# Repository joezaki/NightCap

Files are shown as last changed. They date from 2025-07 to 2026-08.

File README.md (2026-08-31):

# NightCap

> ### NightCap is a tool for constructing custom electrophysiology implants for performing multi-site electrophysiology. Given a set of stereotaxic coordinates for up to 16 brain regions, this pipeline will produce a 3D-printable implant along with a custom electrode interface board (EIB) where holes in both are stereotaxically defined.

#### *Note: NightCap was made initially for performing long-term electrophysiology for sleep studies; however, this tool can be applied as readily to any chronic electrophysiology setup.*
***

## *Procedure*
### *General Overview*

> 1.  First, create a CSV file of stereotaxic locations with the following columns: `['Region', 'AP', 'ML', 'DV', 'Type']`.
> 1. Type should be one of `['LFP', 'GND', 'REF', 'EEG', 'EMG']`.
> 1. Save this file to the `StereotaxCoords` folder.
> 1. Proceed to `Implant` instructions below to construct the 3D-printable implant.
> 1. Proceed to `PCB`, `Bottom PCB`, and `Top PCB` instructions to construct the bottom and top PCBs.
> 1. Proceed to `Assembly` to put everything together.<br>
> *Note: Images below are examples from running the pipeline on the CSV provided in the repo: `./StereotaxCoords/CTX_TH_HPC_Bilateral_16Ch.csv`*

***

### *Implant*
> 1. We will be using OpenSCAD to construct the 3d-printable STL files. [Install OpenSCAD here.](https://openscad.org) *Note that you may first have to allow your computer to trust the program before you can open it.*
> 1. In the `Implant` sub-folder, open the `generate_implant.py` file in a text editor. In the `Specify parameters` section, update `brain_regions_csv` with the filename of your stereotaxic coordinates file. Modify any other parameters of interest here.
> 1. Open a terminal window, navigate to where you cloned the `NightCap` folder: `cd ~/path/to/NightCap`
> 1. Create the conda environment: `conda env create -f environment.yml`<br>*Note: If you do not have conda installed on your computer, [install Anaconda here](https://anaconda.org) first.*
> 1. Activate environment: `source activate nightcap`
> 1. Execute script: `python generate_implant.py`. It may take a few minutes to run. The terminal window will print statements as the pipeline progresses.
> 1. A folder called `./GeneratedFiles/Implant` should have been created. Check inside this folder for a folder with the current time. Inside this folder should be:

| File/Folder | Description |
| --- | --- |
| `implant.stl` & `depth_guide.stl` | 3D-printable STL files |
| `implant.scad` & `depth_guide.scad` | SCAD files for constructing STL files |
| `regions.csv` | original stereotaxic coordinates CSV |
| `implant_depth_guide.html`  | interactive visualization of the stl files for the implant and depth guide |
| `2d_implant.html` & `3d_implant.html`  | interactive visualizations of the implant mapping |
| `3d_implant_animation.gif` | GIF of the 3D rotating implant for presentations (optional) |

<div align="center">
    implant_depth_guide<br>
    2d_implant<br>
    3d_implant<br>
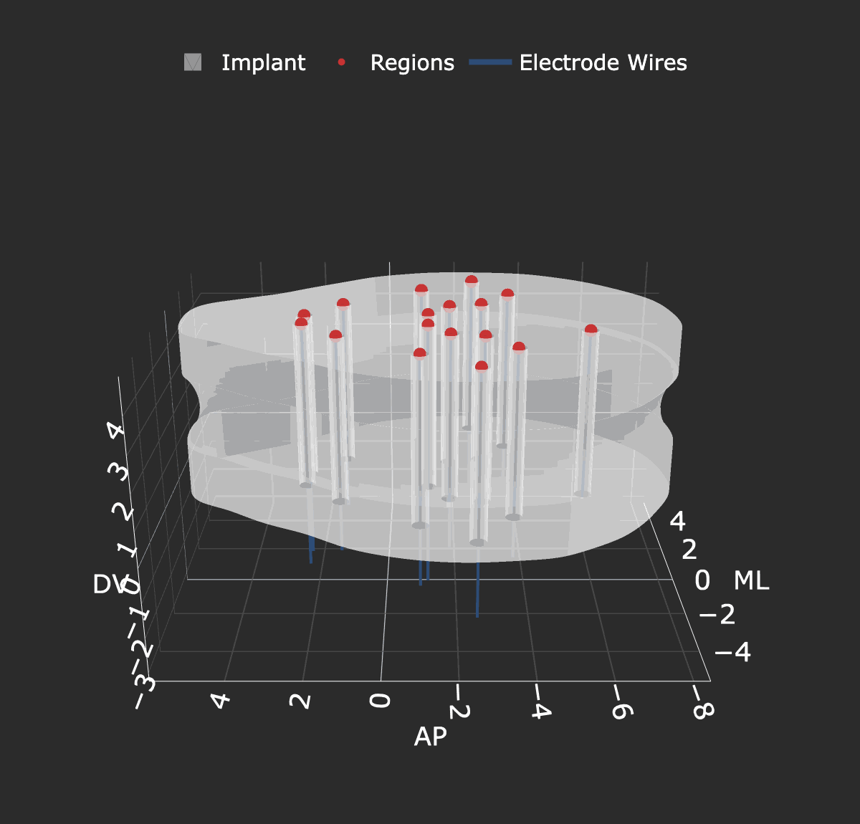
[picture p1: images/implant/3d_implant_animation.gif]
3d_implant_animation
    
</div>

***

### *PCB*
> 0. Only perform the following two steps prior to first use of this pipeline:
> 1. For PCB construction, we will use the KiCad software. [Install KiCad here.](https://kicad.org)
> 1. After installing KiCad, install the Freerouting plugin:
> > - Open KiCad
> > - `Tools -> Plugin and Content Manager`
> > - Find "Freerouting" and install.
> > - Click "Apply Pending Changes"
> > - [Install Java here.](https://adoptium.net/temurin/releases)
> > - After installation, restart KiCad.

***

### *Bottom PCB*
> 1. In the `BottomPCB` subfolder, open `generate_bottom_pcb.py` file in a text editor. In the `Specify parameters` section, update `brain_regions_csv` with the filename of your stereotaxic coordinates file. Modify any other parameters of interest here.
> 1. In KiCad, open project by clicking on `.../NightCap/PCB/BottomPCB/BottomPCB.kicad_pro`
> 1. Click on PCB Editor. A blank window should pop up.
> 1. `Tools -> Scripting Console`
> 1. Execute script: `exec(open('./generate_bottom_pcb.py').read())`
> 1. A folder should have been created in `./GeneratedFiles/BottomPCB/` with the current time. Inside this folder should be:

| File/Folder | Description |
| --- | --- |
| `NightCap_BottomPCB_JLCPCB_Production.zip` | main file to upload to JLCPCB for PCB construction |
| `NightCap_BottomPCB_Gerbers/` | folder with gerber files for PCB construction |
| `channel_map.csv` | mapping between each brain region and the EIB channel |
| `autoroute.ses` | file with autorouting track data |
| `figures/` | folder with visualizations of PCB |

<div align="center">
    bottom_pcb_top_view
    bottom_pcb_bottom_view
</div>

***

### *Top PCB*
> 1. In the `TopPCB` subfolder, open `generate_top_pcb.py` file in a text editor. In the `Specify parameters` section, update `which_connector` to be one of `['molex', 'omnetics']`. Modify any other parameters of interest here.
> 1. In KiCad, open project by clicking on `.../NightCap/PCB/TopPCB/TopPCB.kicad_pro`
> 1. Click on PCB Editor. A blank window should pop up.
> 1. `Tools -> Scripting Console`
> 1. Execute script: `exec(open('./generate_top_pcb.py').read())`
> 1. A folder should have been created in `./GeneratedFiles/TopPCB/` with the current time. Inside this folder should be:

| File/Folder | Description |
| --- | --- |
| `NightCap_TopPCB_JLCPCB_Production.zip` | main file to upload to JLCPCB for PCB construction |
| `NightCap_TopPCB_Gerbers/` | folder with gerber files for PCB construction |
| `NightCap_TopPCB_BOM.csv` | file for bill of materials for connector (molex or omnetics) |
| `NightCap_TopPCB_positions.csv` | file placement position for connector onto PCB |
| `autoroute.ses` | file with autorouting track data |
| `figures/` | folder with visualizations of PCB |

<div align="center">
    top_pcb_top_view
    top_pcb_bottom_view
</div>

***

### *Assembly*
> 0. After following the steps above, the implant and depth guide need to be 3D-printed (we use the FormLabs Form4), and the Top and Bottom PCBs need to be constructed (we use [JLCPCB](https://jlcpcb.com)).
> 1. Once implant, depth guide, top PCB, and bottom PCB have been created, the whole implant needs to be assembled.
> 1. First, take wire of your choosing (we have been using [Stablohm 650 wire](https://calfinewire.com/item/alloys/all-alloys/100187-stablohm-650-wire) for LFP wires and [PFA-Coated Silver Wire 786000](https://www.a-msystems.com/p-796-pfa-coated-silver-wire.aspx) for EEG and EMG wires).
> 1. Cut each wire to ~20mm long using sharp scissors, and strip 1mm of insulation off one end of each wire. This side will connect to the bottom PCB.
> 1. Feed header pins into each outer via on the bottom PCB and solder into place.
> 1. Attach implant onto bottom PCB.
> 1. Secure depth guide onto the implant. Look top down through the bottom PCB to make sure that all the holes align.
> 1. Feed each wire through the holes in the bottom PCB. They should feed cleanly through the bottom PCB, implant, and depth guide. Solder them in place.
> 1. Line up the top PCB over the bottom PCB using the header pins. Solder the pins in place.
> 1. At this point, the impedance of each electrode is tested by submerging the signal and ground wires into saline and running a program to test impedances.
> 1. Snip the wires to length at the point at which they exit the depth guide, using sharp scissors.
> 1. Remove the depth guide.
> 1. The implant is now ready for implantation. Finally, the implant is surgically implanted into the subject for recording.

### Happy recording! :sparkles:

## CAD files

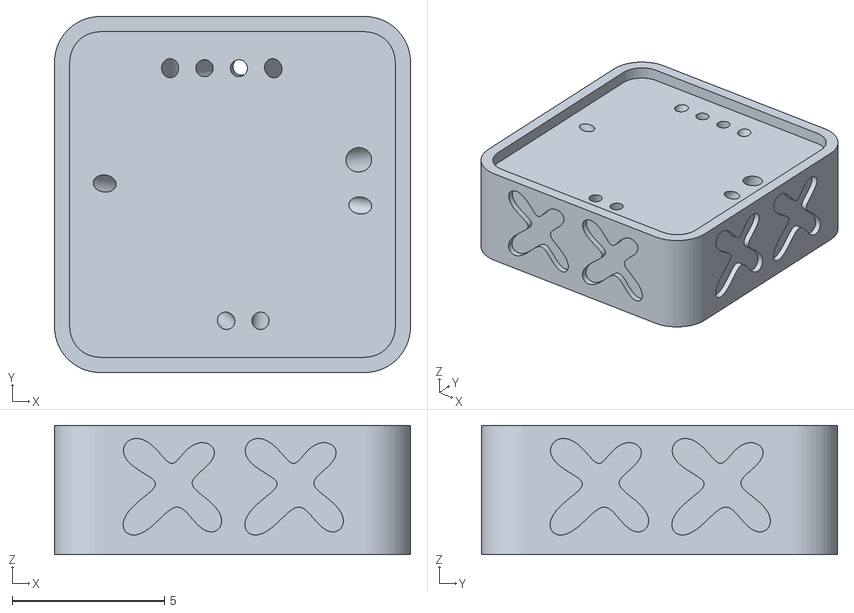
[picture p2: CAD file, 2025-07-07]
EIB16MouseImplantCompleted.stl
11.7 x 11.7 x 4.25

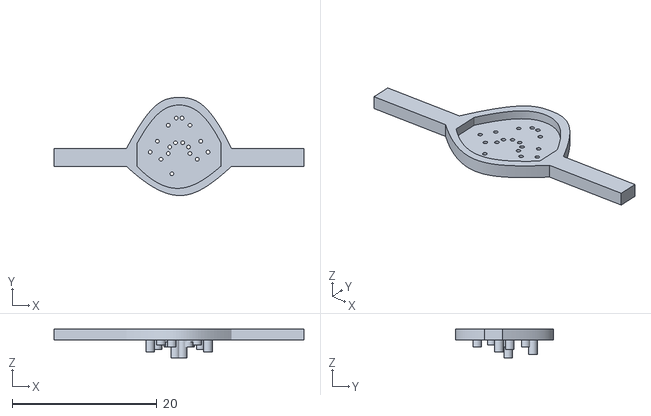
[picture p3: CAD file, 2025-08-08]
DepthTestCortex2_8825.stl
34.6 x 13.6 x 4.00

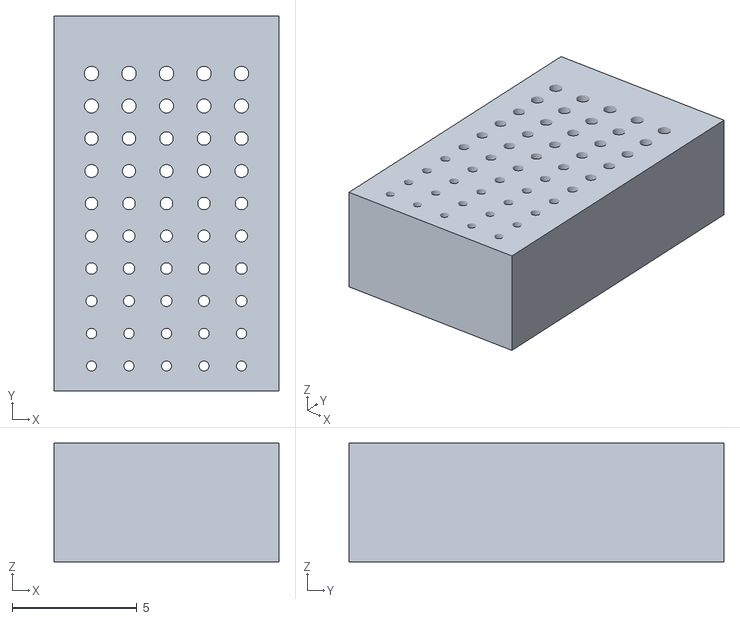
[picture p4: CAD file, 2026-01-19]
Implant/3D_PrinterTests/NightCap_HoleSizeTest_0.20_0.29_range.stl
9.00 x 15.0 x 4.75

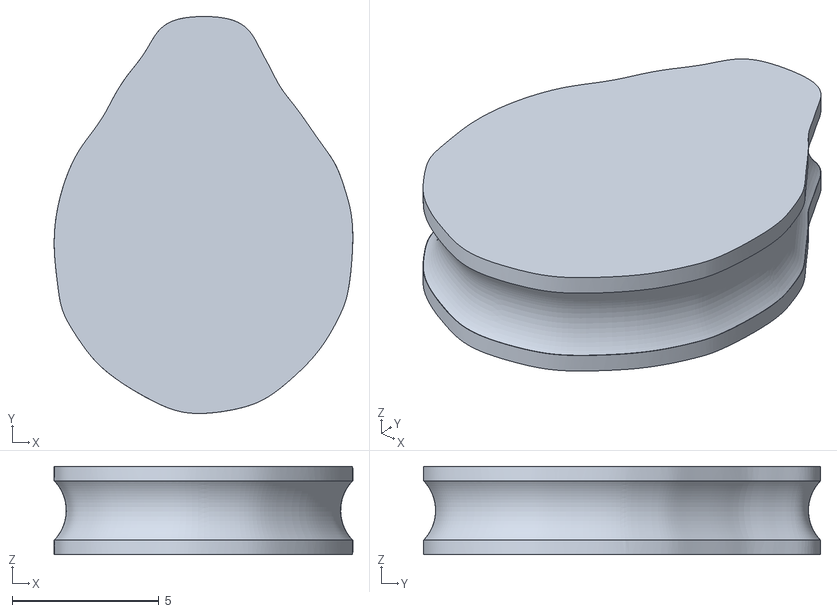
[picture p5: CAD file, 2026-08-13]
Implant/SCAD_Files/ImplantBlank_H3mm.stl
10.2 x 13.5 x 3.00

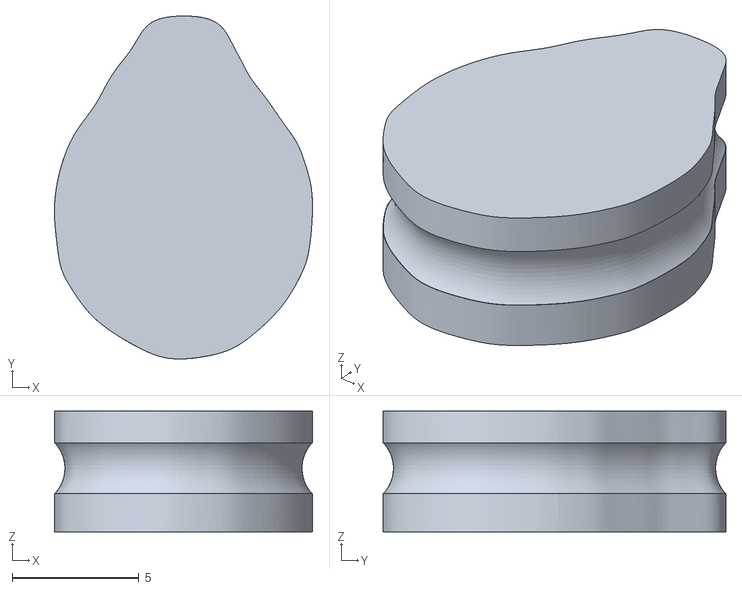
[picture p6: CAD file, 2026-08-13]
Implant/SCAD_Files/ImplantBlank_H4_75mm.stl
10.2 x 13.5 x 4.75

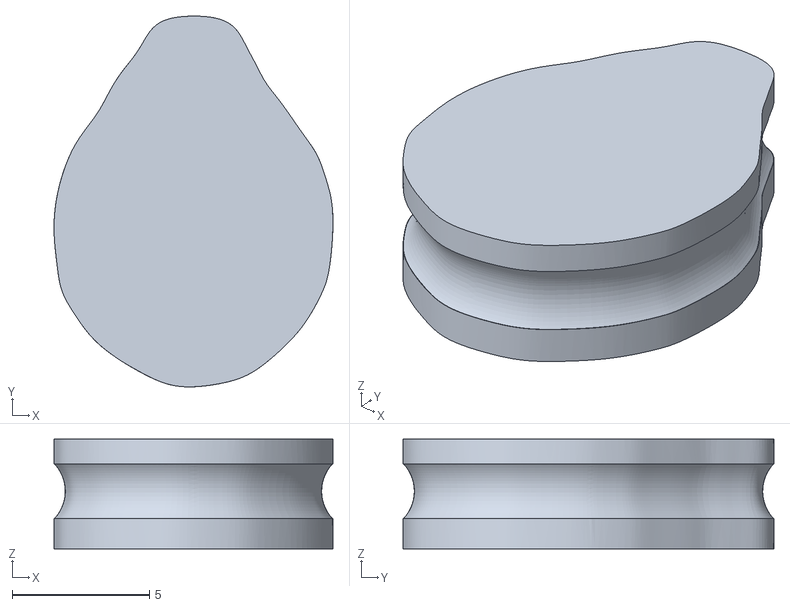
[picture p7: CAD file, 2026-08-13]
Implant/SCAD_Files/ImplantBlank_H4mm.stl
10.2 x 13.5 x 4.00

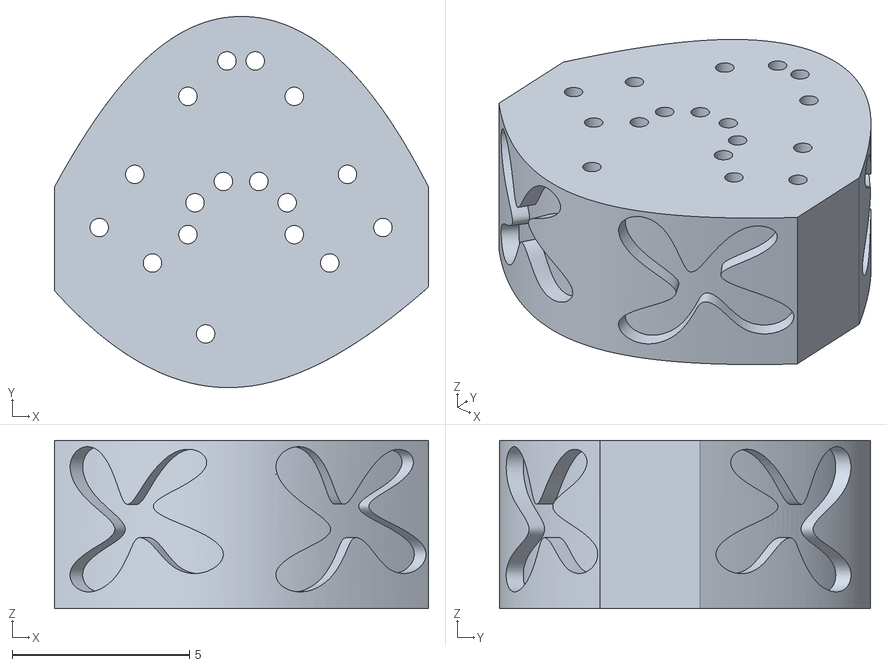
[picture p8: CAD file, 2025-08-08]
ImplantTestCortex2_8825.stl
10.5 x 10.5 x 4.75

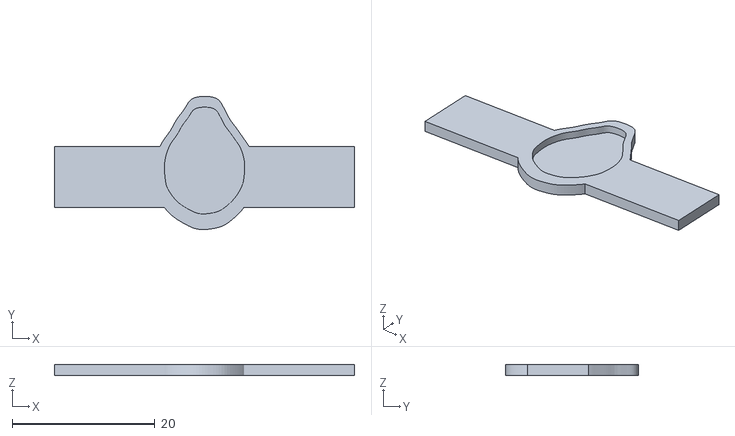
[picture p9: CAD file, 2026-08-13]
Implant/SCAD_Files/DepthGuideBlank.stl
42.1 x 18.7 x 1.50

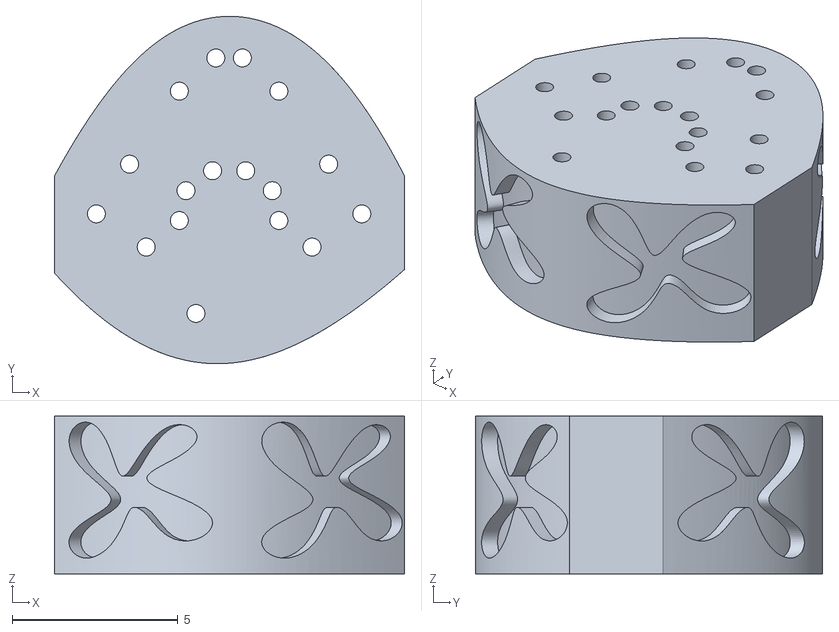
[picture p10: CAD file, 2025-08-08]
ImplantTestCortex_8825.stl
10.5 x 10.5 x 4.75

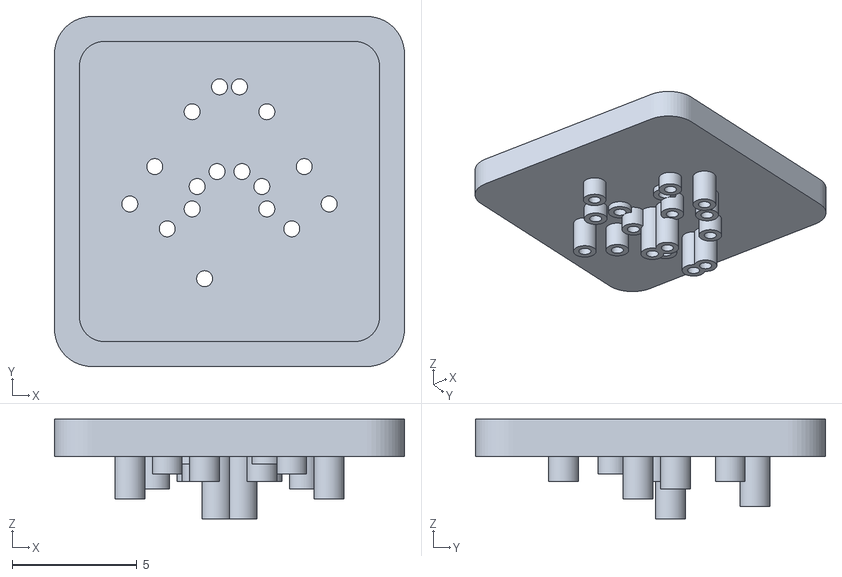
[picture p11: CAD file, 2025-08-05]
DepthTestCortex_8525.stl
14.1 x 14.1 x 4.00

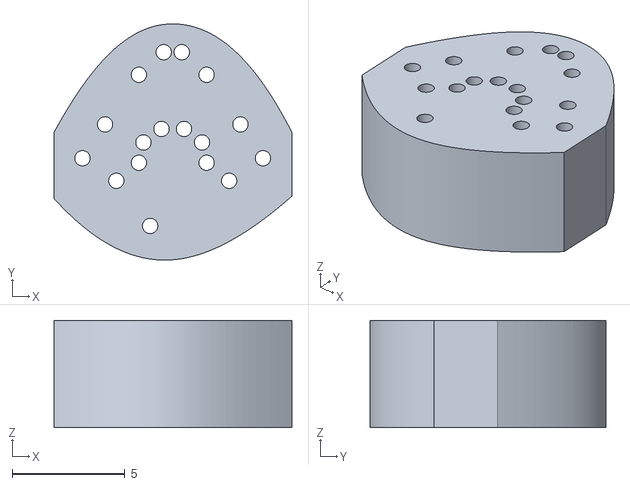
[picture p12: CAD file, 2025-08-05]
ImplantTestCortex_8525.stl
10.5 x 10.5 x 4.75

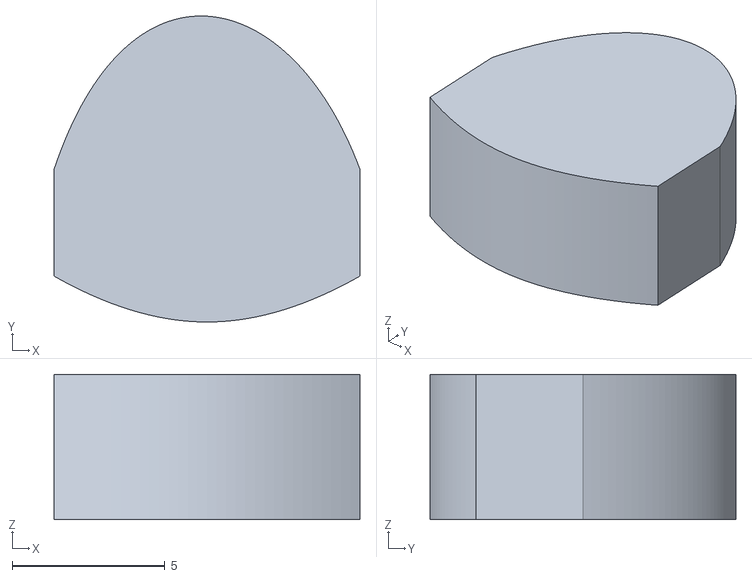
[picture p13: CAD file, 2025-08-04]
BlankMouseImplantShapedv1.stl
10.0 x 10.0 x 4.75

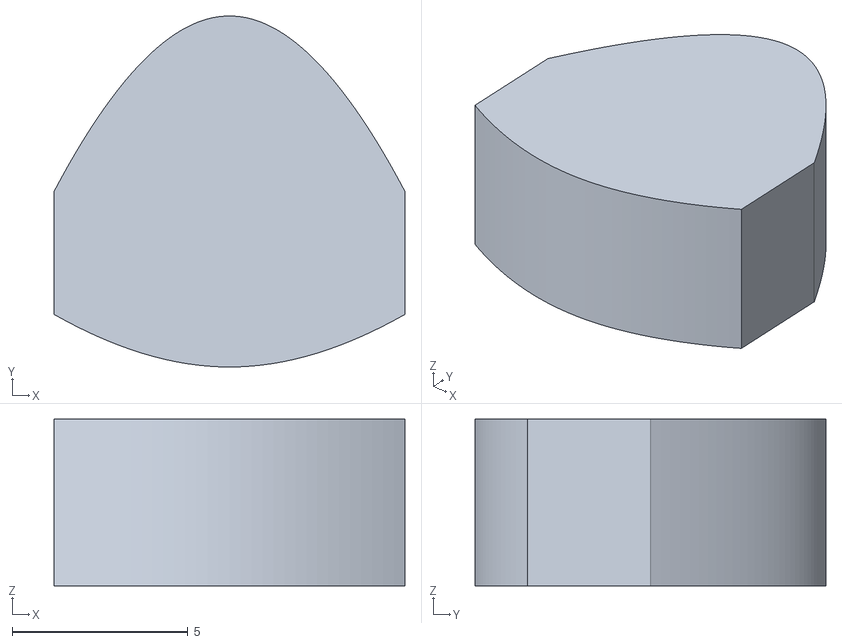
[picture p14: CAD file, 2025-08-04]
BlankMouseImplantShapedv0.stl
10.0 x 10.0 x 4.75

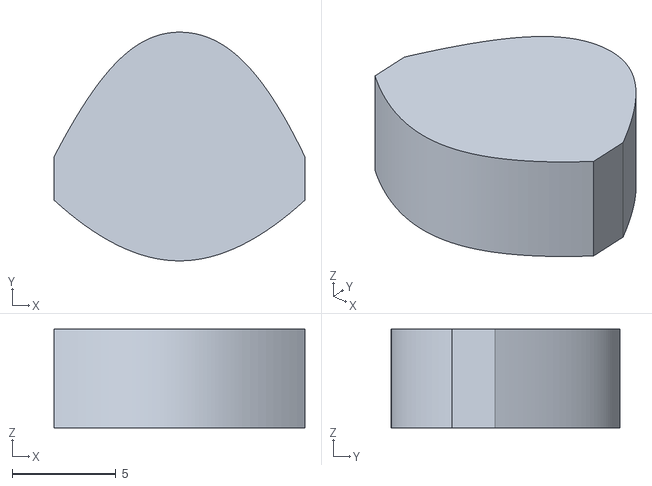
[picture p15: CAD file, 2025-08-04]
BlankMouseImplantShapedv2.stl
12.1 x 11.0 x 4.75

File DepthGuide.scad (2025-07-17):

difference() {
import("BlankDepthGuidev6.stl");


translate([1.3000, 0.0000, -1.5000])
    cylinder(h = 10, r = 0.34, $fn=60);

translate([-1.3000, 0.0000, -1.5000])
    cylinder(h = 10, r = 0.34, $fn=60);

translate([0.4000, 4.2000, -2.5000])
    cylinder(h = 10, r = 0.34, $fn=60);

translate([-0.4000, 4.2000, -2.5000])
    cylinder(h = 10, r = 0.34, $fn=60);

translate([2.0000, 2.5000, -3.5000])
    cylinder(h = 10, r = 0.34, $fn=60);

translate([-2.0000, 2.5000, -3.5000])
    cylinder(h = 10, r = 0.34, $fn=60);

translate([1.0000, -3.5000, -2.0000])
    cylinder(h = 10, r = 0.34, $fn=60);

translate([-1.0000, -3.5000, -2.0000])
    cylinder(h = 10, r = 0.34, $fn=60);

translate([3.0000, 1.0000, -1.8000])
    cylinder(h = 10, r = 0.4, $fn=60);

}

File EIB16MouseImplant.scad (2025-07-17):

difference() {
// Import your STL model
import("BlankMouseImplantv3.stl");

// Hole from [4.2, -0.36, 4.75] to [1.3, 0.0, -1.5]
translate([1.2205, 0.0099, 2.0000])
rotate(a = 46.7395, v = [0.1232, 0.9924, -0.0000])
    cylinder(h = 5.2127, r = 0.34, $fn=60);
translate([1.3000, 0.0000, 0])
        cylinder(h = 2.232, r = 0.34, $fn=60);
// Hole from [-4.2, 0.36, 4.75] to [-1.3, 0.0, -1.5]
translate([-1.2205, -0.0099, 2.0000])
rotate(a = 46.7395, v = [-0.1232, -0.9924, 0.0000])
    cylinder(h = 5.2127, r = 0.34, $fn=60);
translate([-1.3000, 0.0000, 0])
        cylinder(h = 2.232, r = 0.34, $fn=60);
// Hole from [0.21, 4.15, 4.75] to [0.4, 4.2, -2.5]
translate([0.4076, 4.2020, 2.0000])
rotate(a = 4.0865, v = [0.2545, -0.9671, -0.0000])
    cylinder(h = 3.9570, r = 0.34, $fn=60);
translate([0.4000, 4.2000, 0])
        cylinder(h = 2.232, r = 0.34, $fn=60);
// Hole from [-0.92, 4.15, 4.75] to [-0.4, 4.2, -2.5]
translate([-0.3796, 4.2020, 2.0000])
rotate(a = 10.7559, v = [0.0957, -0.9954, -0.0000])
    cylinder(h = 3.9992, r = 0.34, $fn=60);
translate([-0.4000, 4.2000, 0])
        cylinder(h = 2.232, r = 0.34, $fn=60);
// Hole from [1.34, 4.15, 4.75] to [2, 2.5, -3.5]
translate([2.0222, 2.4446, 2.0000])
rotate(a = 32.8713, v = [-0.9285, -0.3714, 0.0000])
    cylinder(h = 4.4742, r = 0.34, $fn=60);
translate([2.0000, 2.5000, 0])
        cylinder(h = 2.232, r = 0.34, $fn=60);
// Hole from [-2.05, 4.15, 4.75] to [-2, 2.5, -3.5]
translate([-1.9983, 2.4434, 2.0000])
rotate(a = 30.9754, v = [-0.9995, -0.0303, 0.0000])
    cylinder(h = 4.4074, r = 0.34, $fn=60);
translate([-2.0000, 2.5000, 0])
        cylinder(h = 2.232, r = 0.34, $fn=60);
// Hole from [0.92, -4.15, 4.75] to [1, -3.5, -2]
translate([1.0031, -3.4747, 2.0000])
rotate(a = 13.3953, v = [0.9925, -0.1222, -0.0000])
    cylinder(h = 4.0269, r = 0.34, $fn=60);
translate([1.0000, -3.5000, 0])
        cylinder(h = 2.232, r = 0.34, $fn=60);
// Hole from [-0.21, -4.15, 4.75] to [-1, -3.5, -2]
translate([-1.0296, -3.4756, 2.0000])
rotate(a = 20.4058, v = [0.6354, 0.7722, -0.0000])
    cylinder(h = 4.1341, r = 0.34, $fn=60);
translate([-1.0000, -3.5000, 0])
        cylinder(h = 2.232, r = 0.34, $fn=60);
// Ground hole from [4.15, 1.14, 4.75] to [3, 1, -1.8]
translate([2.9576, 0.9948, 2.0000])
rotate(a = 22.8442, v = [-0.1208, 0.9927, -0.0000])
    cylinder(h = 4.1841, r = 0.4, $fn=60);
translate([3.0000, 1.0000, 0])
    cylinder(h = 2.232, r = 0.4, $fn=60);

}

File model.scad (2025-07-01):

// Import mouse skull
translate([-15.3, -14.00, 1]) {
    rotate([-1.4, 90, 0])
        import("files/Mouse_Skull.stl");
}

// Load your STL
translate([0, 0, 1]) {
    import("MouseBoxEIB16.stl");
}

// Electrode holes

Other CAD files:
DepthTestCortex_8825.stl
ImplantTestCortex_8425.stl
DepthTestCortex_8425.stl
DepthTestCortex_73125.stl
model2.scad
BlankDepthGuide.stl
BlankDepthGuidev2.stl
BlankDepthGuidev3.stl
BlankDepthGuidev4.stl
BlankDepthGuidev5.stl
BlankDepthGuidev6.stl
BlankDepthGuidev7.stl
BlankMouseImplant.stl
BlankMouseImplantv2.stl
BlankMouseImplantv3.stl
DepthGuide.stl
DepthTest1_71425.stl
DepthTest1_7825.stl
DepthTest2_71425.stl
DepthTest2_7825.stl
DepthTestCortex_72725.stl
DepthTestCortex_72825.stl
DepthTestCortex_8125.stl
DepthTest_71625.stl
DepthTest_71825.stl
EIB16MouseImplant.stl
HoleCheck.stl
HoleCheckBlank.stl
ImplantTest1_71425.stl
ImplantTest1_7825.stl
ImplantTest2_71425.stl
ImplantTest2_7825.stl
ImplantTestCortex_72725.stl
ImplantTestCortex_72825.stl
ImplantTestCortex_73125.stl
ImplantTestCortex_8125.stl
ImplantTest_71625.stl
ImplantTest_71825.stl
ImportTrial.scad
MouseBox2_v1.stl
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

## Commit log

2025-07-01 Added locations of each electrode for the EIB 16 board and changed fusion accordingly.
    [MouseBoxEIB16 v1.f3d, MouseBoxEIB16.stl, model.scad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]
2025-07-01 Added vertical cylinders to the bottom and finished sizing for implant. A solid prototype. This size only works for brain regions 0.3 mm or more apart. Still have not finished tool that fits below an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
    [BlankMouseImplant.stl, model2.scad, model2.stl]
2025-07-02 Minor name change
    [EIB16MouseImplant.scad, EIB16MouseImplant.stl]
2025-07-02 Got the Depth Guide and the EIB16 with the grounding. Everything looks good. Worried about the weight also have a VolumeCheck.py to check weight.
    [BlankDepthGuide.stl, DepthGuide.scad, DepthGuide.stl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]
2025-07-02 Made some changes to grounding.
    [DepthGuide.scad, DepthGuide.stl, EIB16MouseImplant.scad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]
2025-07-07 Maximized hole size and changed design.
    [BlankDepthGuidev2.stl, BlankMouseImplantv2.stl, DepthGuide.scad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]
2025-07-08 HoleCheck files for printing
    [HoleCheck.scad, HoleCheck.stl, HoleCheckBlank.stl]
2025-07-09 Tests for 7/8/25
    [DepthGuide.scad, DepthTest1_7825.stl, DepthTest2_7825.stl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]
2025-07-14 Changed height by 1mm and changed size of depth guide for tighter fit.
    [BlankDepthGuidev3.stl, BlankDepthGuidev4.stl, BlankDepthGuidev5.stl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]
2025-07-17 Test for 7/17 and made the transition from vertical to diagonal tube better.
    [BlankDepthGuidev6.stl, DepthGuide.scad, DepthTest_71625.stl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]
2025-07-28 New Cortex test. 16 channels. Increased verticle change in the verticle columns but lowered the desired z height from 2mm to 1mm.
    [DepthGuideCortex.scad, DepthTestCortex_72725.stl, DepthTestCortex_72825.stl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]
2025-07-31 Changed DepthGuide and added new test.
    [DepthGuideCortex.scad, DepthTestCortex_73125.stl, ImplantTestCortex_73125.stl]
2025-07-31 Update to depthguide again
    [DepthGuideCortex.scad, DepthTestCortex_73125.stl, ImplantTestCortex_73125.stl]
2025-08-01 Updated depthguide x2
    [BlankDepthGuidev7.stl, DepthGuideCortex.scad, DepthTestCortex_73125.stl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]
2025-08-04 Made alterations to implant and added labels and label placing algorithmn.
    [BlankMouseImplantShapedv0.stl, BlankMouseImplantShapedv1.stl, BlankMouseImplantShapedv2.stl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]
2025-08-05 Added a little width to columns on depthguide
    [DepthGuideCortex.scad, DepthTestCortex_8425.stl, ImplantTestCortex_8425.stl]
2025-08-05 Added Visual Implant for labels
    [DepthTestCortex_8525.stl, EIB16MouseImplantCortex.scad, ImplantTestCortex_8425.stl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]
2025-08-08 Changes after to depthguide and hole size
    [BlankDepthGuideShapedv0.stl, BlankMouseImplantShapedv4.stl, DepthGuideCortex.scad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]
2025-08-09 Organized the repo and added two possible implants for better fit between depth gudie and implant
    [BlankDepthGuide.stl, BlankDepthGuideShapedv2.stl, BlankDepthGuideShapedv3.stl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]
2025-08-26 Cleaned up repo and added folders for SCAD and blank files and generated files.
    [BlankDepthGuide.stl, BlankDepthGuideShapedv0.stl, BlankDepthGuideShapedv2.stl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]
2025-08-26 add folders for files for eib channel locations, eib boundary vertices, and sets of brain region coordinates
    [CTX_TH_HPC_Bilateral_16Ch.csv, Neuralynx_EIB16.csv]
2025-08-26 move blank implant scad files
    [BlankDepthGuideShapedv4.stl, BlankMouseImplantShapedv4.stl]
2025-11-13 add implant and EIB boundaries for the EIB16-QC-H (Neuralynx magnetic EIB)
    [Neuralynx_EIB16-QC-H.csv, Neuralynx_EIB16-QC-H_FULL.csv]
2026-01-19 add stl file for testing how small the holes can reliably be printed
    [NightCap_HoleSizeTest_0.20_0.29_range.stl]
2026-01-22 change default hole radius based on recent test on new Form4 printer with rigid white resin
2026-02-12 update depth guide hole radius to be slightly larger than the implant hole radius
2026-02-14 fix channel locations and add intan channel mapping to EIB-16-QC-H
    [Neuralynx_EIB16-QC-H.csv, Neuralynx_EIB16-QC-H_FULL.csv]
2026-08-12 update env file to remove cvxpy for channel matching and add pcbnew for pcb creation
2026-08-12 move implant related files to a sub-folder called Implant
    [BlankDepthGuideShapedv4.stl, BlankMouseImplantShapedv4.stl, NightCap_HoleSizeTest_0.20_0.29_range.stl]
2026-08-12 remove EIB_Boundaries and EIBs folders
    [Neuralynx_EIB16-QC-H.csv, Neuralynx_EIB16-QC-H_FULL.csv, Neuralynx_EIB16.csv]
2026-08-12 add CSV files for constructing PCBs
    [EdgeCuts.csv, OuterVias.csv, ViaToPin_Molex.csv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]
2026-08-12 create empty kicad projects for top and bottom PCB
    [BottomPCB.kicad_pcb, BottomPCB.kicad_sch, TopPCB.kicad_pcb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]
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2026-08-13 update SCAD files for implant and depth guide
    [BlankDepthGuideShapedv4.stl, BlankMouseImplantShapedv4.stl, DepthGuideBlank.stl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]
2026-08-13 add column to brain regions csv with channel type
    [CTX_TH_HPC_Bilateral_16Ch.csv]
2026-08-13 remove pcbnew from env file since it will be run through kicad's env, and add numpy-stl for creating the implant mesh
2026-08-13 update generate_implant py file and associated utilities for new NightCap where EIB channel matching is no longer needed and holes are made vertically through implant and depth guide
2026-08-14 update via to through-hole nomenclature in csv files
    [OuterHoles.csv, PTH_To_Pin_Molex.csv, PTH_To_Pin_Omnetics.csv]
2026-08-14 clean up comments, make stereotaxic coords variable consistent with pcb scripts, update args in func calls
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2026-08-15 check if board used inner layers before unnecessarily making empty inner layer gerbers
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2026-08-17 add plot of implant and depth guide stl meshes, reduce marker size in 3d plot, fix rotating gif to look smoother, move final print statement to end of pipeline after rotating gif creation
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2026-08-31 fix hyperlinks, add info about 3d printer and pcb vendor, add tables for generated files and folders, reference sub-folders with relative paths, clean up wording
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
